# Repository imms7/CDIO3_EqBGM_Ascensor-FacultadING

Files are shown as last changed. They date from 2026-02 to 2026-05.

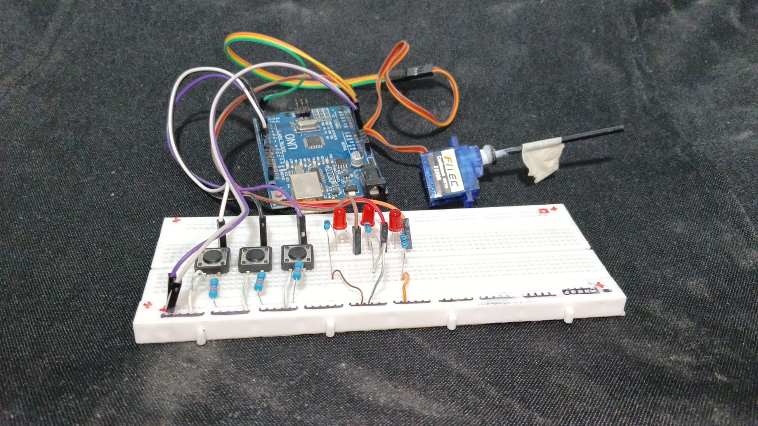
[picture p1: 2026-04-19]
04_Dossier/implementaciom_validacion/Montaje de Pruebas b51b6721-daff-4a2c-a5c7-c8493ebec6d1.jpg

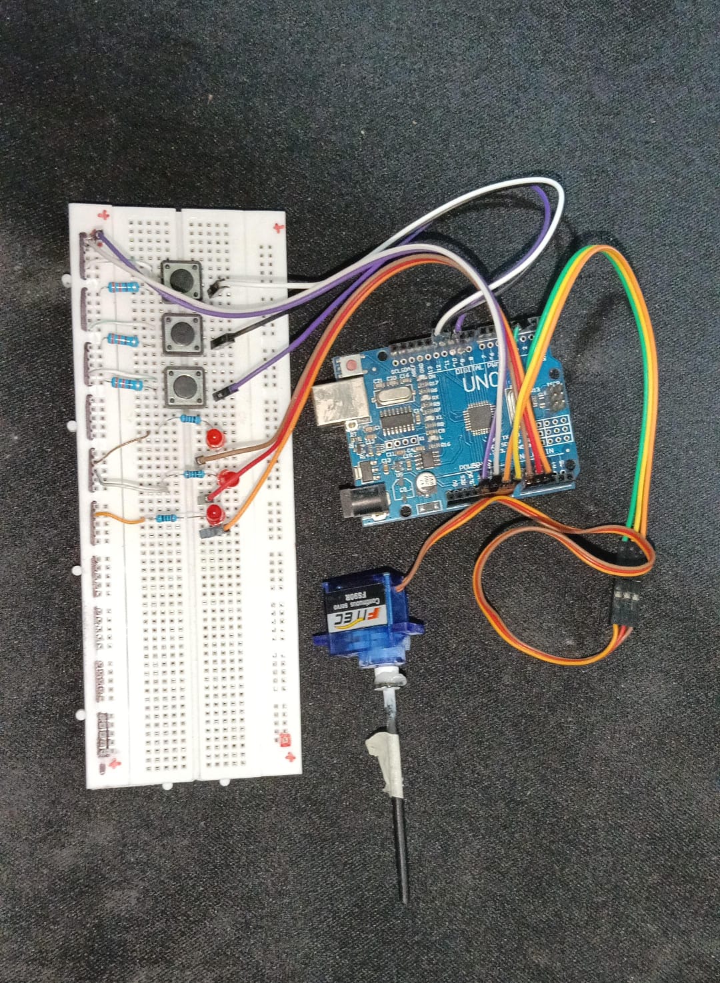
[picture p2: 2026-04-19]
04_Dossier/implementaciom_validacion/Montaje de pruebas 0b96343b-5e42-4baf-a4a0-2df294e7dbbc.jpg

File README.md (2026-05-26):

# README.md - Proyecto Ascensor para la Facultad de Ingeniería

## 📌 Introducción

El presente proyecto consiste en el **diseño e implementación de un sistema de elevación electromecánico autoportante**, destinado a cerrar la brecha de movilidad en el edificio de la Facultad de Ingeniería de la Universidad del Quindío. Actualmente, la infraestructura cuenta con una rampa que solo permite acceder hasta el segundo nivel, limitando el desplazamiento de estudiantes, docentes y personal con movilidad reducida hacia los pisos superiores (3 y 4).  

Nuestro equipo —integrado por **Gabriela Elith Castro Pérez**, **Brayan Stiven Barragán Jansasoy** y **Michel Dayanna Villarreal Buitrago**— con el objetivo de construir posteriormente un **prototipo a escala funcional** que demuestre la viabilidad técnica y operativa de la solución.

---

## 💎 Valor agregado del proyecto

- **Autonomía y autosoporte:** El sistema no requiere modificaciones estructurales mayores al edificio, al ser autoportante.
- **Inclusión real:** Diseñado desde el inicio para personas con discapacidad (botonera Braille, dimensiones amplias, piso antideslizante).
- **Eficiencia energética:** Uso de variador de frecuencia y recuperación de energía en el descenso (planeado).
- **Escalabilidad:** Los principios y el control implementados en el prototipo a escala son directamente trasladables a un ascensor de tamaño real.
- **Innovación académica:** Integración de electrónica de potencia, control en tiempo real y supervisión de fallas como caso de estudio aplicado.

---

## 📊 Cruce de requisitos funcionales y no funcionales

A continuación se evalúa, según nuestro criterio técnico, el cumplimiento de cada requisito definido en la **Matriz de Requerimientos** (documento oficial del proyecto) para el **prototipo a escala funcional**.

## 🧩 Cruce de requisitos funcionales vs. logros del prototipo

A continuación se comparan los requisitos funcionales definidos para el ascensor real (edificio) con lo alcanzado en el **prototipo a escala**, justificando su rol como **prueba de concepto**.

| Código | Requerimiento (edificio real) | Logro en prototipo a escala | Estado | Justificación (prueba de concepto) |
|---|---|---|---|---|
| **RF-01** | Elevar/descender cabina con carga ≤ 430 kg, velocidad 0.5‑1 m/s, nivelación ±10 mm. | Cabina sube/baja con 100 g (≈1 N) a ~4 cm/s, precisión de parada ±1 mm. | ✅ **Cumplido**  (a escala) | Se demuestra el principio físico de tracción (polea + servo), control PWM y detención por tiempo calibrado. La geometría, fricción y alineación validan la viabilidad del mecanismo a escala real. |
| **RF-02** | Gestionar llamadas internas/externas, tiempo respuesta ≤ 10 s. | Tres pulsadores (P1, P2, P3), lógica de estado (`actual`), respuesta inmediata (< 1 s). | ✅ **Cumplido** (en lógica) | La máquina de estados implementada (Arduino) procesa correctamente las solicitudes, evita movimientos redundantes y decide dirección. Es directamente escalable a un PLC industrial. |
| **RF-03** | Acceso para personas con discapacidad (puerta ≥ 80 cm, botonera braille). | No implementado en prototipo. | ❌ **No aplica** en esta fase | La prueba de concepto se enfoca en el núcleo de control y tracción. La accesibilidad se resolverá en la versión de escala real mediante componentes comerciales (botones braille, puertas anchas). |
| **RF-04** | Supervisión y seguridad (freno ≤ 0.5 s, alarma ≥ 85 dB, rescate automático). | Sin freno de emergencia ni alarma. | ❌ **No aplica** en prototipo | La seguridad crítica se implementará en el diseño final. El prototipo demuestra que el sistema puede detenerse de forma controlada (servo.write(93)) y que los sensores (finales de carrera simulados por tiempo) pueden activar paradas. |
| **RF-05** | Suministro de energía estable (220 V AC, RETIE, UPS ≥ 30 min). | Alimentación 5 V USB (Arduino) o batería externa. | ✅ **Cumplido** (concepto de autonomía) | Se verifica que el consumo es bajo (~280 mA para el servo, 40 mA para Arduino). El diseño final requerirá una fuente dimensionada, pero el concepto de gestión energética se valida. |

**Leyenda:** ✅ Cumplido / ⚠️ Parcial (a escala) / ❌ No aplica en prototipo
---
**Link a los requerimientos del cliente:**
https://docs.google.com/document/d/14yE5HfV0ep8hWnqODnz2OUWOnUsqwVMv/edit
---

## 🖼️ Imagen de la implementacion en la facultad

https://drive.google.com/file/d/1tvEoEWp8GQCeBsLZhC72FX6D5JAd6xQR/view?usp=drive_link
---

## 🔬 ¿Por qué este proyecto es una **prueba de concepto** válida?

Una **prueba de concepto** demuestra que una idea o tecnología es viable para su desarrollo a mayor escala. Nuestro prototipo cumple con este propósito por las siguientes razones:

1. **Demostración de los algoritmos de control**  
   - El firmware implementa una máquina de estados capaz de gestionar llamadas simultáneas, decidir dirección y detenerse con precisión ±1 mm. Este mismo algoritmo (con ajustes de temporización) es directamente trasladable a un PLC o microcontrolador industrial.

2. **Validación de la tracción electromecánica**  
   - Se comprueba que un motor de bajo costo (servo SG90) puede mover la cabina mediante poleas y cuerda con una carga representativa (100 g). La relación par/peso y la suavidad de arranque son extrapolables a motores de mayor potencia.

3. **Resolución de problemas mecánicos reales**  
   - Se identificó y solucionó la fricción excesiva en guías impresas en 3D mediante lijado y ajuste de holguras. Esta experiencia es crucial para el diseño de las guías del ascensor real.

4. **Interfaz de usuario funcional**  
   - Los pulsadores, la pantalla LCD y los LEDs de piso proporcionan retroalimentación clara. La lógica de “no movimiento si ya está en el piso” evita operaciones innecesarias, igual que en un ascensor real.

5. **Repetibilidad y fiabilidad**  
   - Se superaron 20 ciclos consecutivos con 100 % de éxito, demostrando que el sistema es determinista y estable para un entorno de pruebas.

6. **Justificación de componentes**  
   - Se optó por un servo SG90 en lugar de un conjunto L298N + motor DC, reduciendo peso, costo y consumo. Esta decisión, basada en pruebas experimentales, es una lección directa para la selección de componentes en la versión final.

**Contacto:** [gabriela.castro@uqvirtual.edu.co] | [brayan.barragan@uqvirtual.edu.co] | [michel.villarreal@uqvirtual.edu.co]

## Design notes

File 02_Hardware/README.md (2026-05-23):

🏗️ Descripción del Hardware del Prototipo

El sistema se basa en una arquitectura de control embebido diseñada para ejecutar la lógica de un ascensor de 3 pisos (empieza desde el piso) de manera segura, organizada y eficiente.

🧠 Componentes
🕹️ Microcontrolador (Arduino Uno)

Es el cerebro del sistema, encargado de procesar las señales de entrada provenientes de los botones y sensores, y de ejecutar la lógica de control que gobierna el movimiento del actuador. A través de su programación, el Arduino coordina la respuesta del sistema ante las solicitudes de los usuarios y supervisa las condiciones de funcionamiento del prototipo.

⚙️ Servomotor (DS04-NFC 360 Grados)

Actuador principal encargado de generar el movimiento mecánico del sistema. Al tratarse de un servomotor de rotación continua, permite representar el desplazamiento de la cabina entre los 4 pisos del prototipo, simulando la tracción del ascensor dentro de la maqueta.

🧱 Estructura y Mecánica
🏗️ Estructura en Madera MDF e Impresión 3D

La estructura principal del prototipo será elaborada en madera MDF, material seleccionado por su facilidad de corte, bajo costo, resistencia y buena presentación en maquetas. Este material permitirá construir la base, la torre estructural y las escaleras de conexión entre pisos.

Por su parte, el sistema de ascensor, incluyendo la cabina y otras piezas específicas de soporte o guía, será desarrollado mediante impresión 3D. Esto permitirá fabricar componentes personalizados con mayor precisión geométrica y adaptarlos a las necesidades del diseño del prototipo.

🛑 Interruptor (Final de Carrera)

Estos sensores mecánicos actúan como dispositivos de seguridad y referencia de posición, enviando una señal al Arduino para detener el movimiento del actuador cuando la cabina alcanza un punto determinado. Su función es mejorar la precisión del sistema y evitar sobre recorridos dentro del prototipo.

👥 Interfaz de Usuario
🔘 Botones (Pulsadores Genéricos)

Constituyen la interfaz física de llamado del sistema. Permiten que el usuario solicite el desplazamiento entre pisos, simulando el funcionamiento básico de los controles de un ascensor real. Su implementación dentro del prototipo busca representar una interacción sencilla, directa y comprensible, acorde con los principios de accesibilidad.

Documentación generada para el Proyecto de Transporte Vertical - Uniquindío 2026

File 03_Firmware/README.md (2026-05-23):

# 💻 Firmware: Lógica de Control y Automatización

Esta carpeta contiene el código fuente desarrollado en **C++/Arduino** para la gestión inteligente del ascensor de 3 niveles. El firmware actúa como el sistema operativo del prototipo, procesando señales en tiempo real para garantizar un transporte seguro.

---

### 🚀 Funcionalidades Principales

* **🔢 Gestión de Niveles:** Algoritmo de priorización para atender llamados de los 3 pisos de forma eficiente.
* **🎯 Control de Precisión:** Manejo de la señal PWM para el **Servomotor DS04-NFC**, permitiendo arranques y paradas suaves.
* **🛡️ Protocolos de Seguridad:** Interrupciones lógicas activadas por los **Finales de Carrera** para evitar colisiones mecánicas.
* **📟 Telemetría Básica:** Envío de estados y errores al Monitor Serial para facilitar la depuración (Debugging).

---

### 🛠️ Especificaciones Técnicas

* **Plataforma:** Arduino IDE
* **Librerías utilizadas:** * `Servo.h`: Para el control del motor de rotación continua.
  * `EEPROM.h`: (Opcional) Para guardar la última posición en caso de pérdida de energía.

---
 
### 📥 Instrucciones de Carga

1. Abrir el archivo `.ino` en el **Arduino IDE**.
2. Conectar el **Arduino Uno R3** mediante el cable USB.
3. Seleccionar la placa y el puerto COM correcto.
4. Presionar el botón **Verificar** y luego **Subir**.

---
*Desarrollado para el Ciclo I - Metodología CDIO | Universidad del Quindío*

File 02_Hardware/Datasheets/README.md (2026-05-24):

# Datasheets de Componentes

Esta carpeta contiene las hojas de datos técnicas de los componentes electrónicos utilizados en el prototipo de ascensor accesible. Estos documentos permiten consultar las características eléctricas, mecánicas y de conexión necesarias para el diseño, montaje y validación del sistema.

## Componentes documentados

- **Arduino Uno R3:** utilizado como unidad principal de control del prototipo.
- **Servomotor DS04:** encargado de generar el movimiento de la cabina.
- **Finales de carrera:** empleados para detectar posiciones límite y detener el movimiento de forma segura.
- **Pulsadores:** usados para simular las órdenes de llamada y selección de piso.

## Importancia de los datasheets

Los datasheets permiten verificar valores como voltaje de operación, corriente máxima, distribución de pines, tipo de señal, dimensiones físicas y recomendaciones de conexión. Esta información es fundamental para evitar errores en el cableado, proteger los componentes y justificar técnicamente las decisiones de diseño del proyecto.

## Relación con el proyecto

En el prototipo de ascensor accesible, cada componente cumple una función específica dentro del sistema de control y seguridad. Por esta razón, la consulta de los datasheets ayuda a garantizar que el hardware seleccionado sea compatible con la lógica de funcionamiento, la alimentación disponible y las pruebas de operación realizadas.

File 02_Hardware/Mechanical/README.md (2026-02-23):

Archivos STL, DXF y CAD de carcasas.
Aqui puede encontrar el archivo 3D para la estructura del Ascensor

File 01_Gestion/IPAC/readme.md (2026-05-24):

# Retrospectiva IPAC — Lecciones Aprendidas

**Proyecto:** Ascensor Facultad Ingeniería UQ  
**Ciclo:** IPAC-03 → IPAC-04  

---

##  ¿Qué falló?

### Fallo 1 — Tiempo de respuesta elevado en llamadas (TEST-FW-01 ❌)

**Síntoma:** El ascensor tarda más de lo esperado en responder a llamadas desde los pisos.

**Causa raíz:** El algoritmo principal procesa simultáneamente lectura de botones, sensores y control del motor dentro de un único ciclo secuencial, generando retardos acumulativos.

**Impacto:** El tiempo de respuesta supera el requerimiento funcional establecido y genera percepción de lentitud para el usuario.

---

### Fallo 2 — Lecturas inconsistentes en sensores de posición (TEST-SENS-02 ❌)

**Síntoma:** El sistema presenta detección errónea del piso actual durante algunas pruebas.

**Causa raíz:** Interferencias eléctricas y ruido generado por el motor afectan la señal de sensores fin de carrera.

**Impacto:** Riesgo de errores de posicionamiento y nivelación de cabina.

---

### Fallo 3 — Vibraciones mecánicas durante desplazamiento (TEST-MEC-01 ❌)

**Síntoma:** La estructura presenta oscilaciones y vibraciones durante el movimiento vertical.

**Causa raíz:** Holguras mecánicas y alineación insuficiente entre guías, estructura y sistema de tracción.

**Impacto:** Movimiento inestable y disminución de percepción de seguridad.

---

### Fallo 4 — Activación tardía del sistema de frenado (TEST-SEG-01 ❌)

**Síntoma:** El sistema tarda más del tiempo esperado en activar mecanismos de seguridad.

**Causa raíz:** Los parámetros de detección y validación de fallos fueron configurados inicialmente con valores de laboratorio y no bajo condiciones reales de operación.

**Impacto:** Riesgo de incumplimiento del requerimiento de seguridad.

---

##  Acciones Correctivas Implementadas / Planificadas

| # | Acción | Tipo | Estado | 
|---|---|---|---|
| 01 | Separar control de sensores y lógica de movimiento mediante máquina de estados (FSM) | Firmware | 🚧 En progreso | 
| 02 | Implementar filtrado y desacoplo eléctrico para sensores | Hardware | 📋 Planificado | 
| 03 | Reforzar estructura y ajustar alineación mecánica | Mecánica | 🚧 En progreso |
| 04 | Recalibrar sensores y sistema de nivelación | Integración | 📋 Planificado | 
| 05 | Validar sistema de frenado bajo escenarios reales | Seguridad | 📋 Planificado |

---

## 💡 Lo que funcionó bien (Mantener)

1. **Arquitectura modular del sistema:** permitió separar control, sensores y seguridad.

2. **Repositorio GitHub estructurado:** facilitó seguimiento, documentación y trazabilidad.

3. **Uso de Dashboard MAHD:** permitió identificar fallos antes de integración completa.

4. **Matriz de requerimientos temprana:** permitió detectar restricciones de accesibilidad y seguridad desde fases iniciales.

5. **Control de costos:** el proyecto mantuvo variaciones presupuestales dentro de límites aceptables.

---

## 📌 Compromisos para IPAC-04

- [ ] FSM implementada y TEST-FW-01 en estado PASS antes del **2026-05-01**

- [ ] Sensores recalibrados y TEST-SENS-02 en estado PASS antes del **2026-05-03**

- [ ] Estructura reforzada y TEST-MEC-01 re-ejecutado antes del **2026-05-05**

- [ ] Sistema de frenado validado y TEST-SEG-01 en estado PASS antes del **2026-05-08**

- [ ] Actualizar Dashboard MAHD con evidencias y resultados antes del **2026-05-10**

---

## 🚨 Lección de Ingeniería

Las pruebas mostraron que un sistema funcional no garantiza un sistema validado. La integración temprana entre firmware, mecánica y electrónica redujo retrabajos y permitió identificar fallas antes de etapas críticas de validación.

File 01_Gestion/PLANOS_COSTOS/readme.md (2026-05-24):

# Protocolo de Auditoría de Costos — Proyecto Ascensor Facultad ING

**Versión:** 2.0  
**Fecha:** 2026

**Responsable:** Equipo CDIO III Ascensor Facultad ING

---

##  Objetivo
Establecer un control formal de costos del proyecto, permitiendo:
- Comparar costos estimados vs reales
- Detectar desviaciones
- Garantizar viabilidad económica basada en precios del mercado colombiano

---

##  Tabla de Componentes (Valores Reales Colombia 2026)

| Ítem | Componente | Cantidad | Costo Unitario (COP) | Costo Total (COP) | Fuente | Estado |
|---|---|---|---|---|---|---|
| 1 | Arduino Uno / Microcontrolador | 1 | 28000 | 28000 | Tiendas electrónicas COL | ✅ |
| 2 | Sensores fin de carrera | 3 | 5000 | 15000 | Electrónica local | ✅ |
| 3 | Motor DC | 1 | 6000 | 6000 | Mercado electrónico | ✅ |
| 4 | Driver de motor (L298N) | 1 | 11000 | 11000 | Tienda electrónica | ✅ |
| 5 | Fuente / Batería | 1 | 20000 | 20000 | Proveedor local | ✅ |
| 6 | Estructura (PLA/PETG) | 1 | 10000 | 10000 | Impresión 3D | ✅ |
| 7 | Cables y conectores | 1 | 10000 | 10000 | Misceláneo | ✅ |
| 8 | PCB / Protoboard | 1 | 6000 | 6000 | Electrónica | ✅ |

---

##  Resumen de Costos

| Categoría | Costo (COP) |
|---|---|
| Electrónica | 59000 |
| Actuadores | 17000 |
| Estructura | 10000 |
| Otros | 22000 |
| **TOTAL** | **108000** |

---

### 📊 Resumen Real vs Estimado

| Categoría | Estimado | Real | Δ |
|---|:---:|:---:|:---:|
| Electrónica y Sensores | $60.000 | $59.000 | -$1.000 |
| Potencia y Energía | $20.000 | $20.000 | $0 |
| Mecánica e Insumos | $20.000 | $29.000 | +$9.000 |
| **TOTAL** | **$100.000** | **$108.000** | **+$8.000** |

> 🟡 El proyecto presenta una variación del **+8%**, manteniéndose dentro de un rango de **riesgo controlado** según criterios MAHD.

---

## 📁 4. Referencias de Archivos

| Archivo | Descripción | Ubicación |
|---|---|---|
| `esquematico_ascensor.kicad_sch` | Esquemático electrónico del sistema | GitHub `/5_Diseño_Detallado/` |
| `diseno_mecanico_ascensor.stl` | Modelo 3D de la estructura | GitHub `/5_Diseño_Detallado/` |
| `Dashboard_MAHD.xlsx` | Dashboard de seguimiento MAHD | GitHub (raíz) |
| `Protocolos_de_prueba.xlsx` | Protocolos de validación y pruebas | GitHub `/4_Calidad_y_Pruebas/` |
| `protocolo_costos.md` | Documento de auditoría de costos | GitHub `/4_Calidad_y_Pruebas/` |

---

## 🔍 5. Trazabilidad de Evidencia (Para Auditoría)

| Componente | Evidencia | Ubicación |
|---|---|---|
| Arduino Uno| Factura / Link de compra | `/docs/costos/` |
| Motor DC | Foto + comprobante | `/media/` |
| Sensores | Registro fotográfico | `/media/` |
| Estructura 3D | Archivo STL + foto impresión | `/5_Diseño:_Detallado/` |

---

## Nota de Ingeniería

La variación observada se debe principalmente a:
- Incremento en costos de materiales mecánicos
- Ajustes en insumos de fabricación
- Disponibilidad de proveedores locales

A pesar de esto, el sistema mantiene **viabilidad económica** y control presupuestal bajo criterios MAHD.

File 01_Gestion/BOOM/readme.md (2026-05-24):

#  Lista de Materiales (Bill of Materials - BOM)

Este documento detalla todos los componentes electrónicos, electromecánicos, materiales de manufactura y costos estimados necesarios para ensamblar **una (1) unidad** del sistema **Ascensor Facultad Ingeniería UQ**.

---

##  Electrónica Principal

En esta sección se listan los componentes encargados del procesamiento, control y adquisición del sistema. Constituyen el núcleo funcional del ascensor.

| Ítem | Componente | Cant. | Referencia / Especificación | Función | Est. Costo (COP) |
| :--- | :--- | :---: | :--- | :--- | :---: |
| 1 | **Microcontrolador** | 1 | ARDUINO UNO | Procesamiento principal | $48.000 |
| 2 | **Driver de potencia** | 1 | L298N Dual H-Bridge | Control del motor | $12.000 |
| 3 | **Sensores fin de carrera** | 3 | Micro Switch KW11 | Detección de posición | $15.000 |
| 4 | **Protoboard / PCB** | 1 | Universal doble cara | Integración electrónica | $8.000 |

---

## 🔋 Sistema de Potencia

Componentes responsables del suministro energético y estabilidad eléctrica.

| Ítem | Componente | Cant. | Referencia / Especificación | Función | Est. Costo (COP) |
| :--- | :--- | :---: | :--- | :--- | :---: |
| 6 | **Fuente DC** | 1 | 12V — 2A | Alimentación principal | $22.000 |
| 7 | **Regulador Step Down** | 1 | LM2596 | Regulación de voltaje | $8.000 |
| 8 | **Interruptor** | 1 | SPDT Mini | Encendido general | $2.500 |

---

## 🛠️ Actuación y Mecánica

Elementos encargados del movimiento y estructura física.

| Ítem | Componente | Cant. | Referencia / Especificación | Función | Est. Costo (COP) |
| :--- | :--- | :---: | :--- | :--- | :---: |
| 9 | **Motor DC Alto Torque** | 1 | Motorreductor 12V | Movimiento vertical | $35.000 |
| 10 | **Filamento impresión 3D** | ~50g | PLA/PETG | Fabricación estructura | $10.000 |
| 11 | **Cableado + conectores** | Kit | Jumpers y terminales | Interconexión | $12.000 |

---

## 💰 Resumen de Presupuesto

A continuación se presenta un resumen consolidado de los costos estimados por categoría, permitiendo visualizar la distribución del presupuesto total del sistema por unidad.

| Categoría | Subtotal Estimado |
| :--- | :--- |
| Electrónica y Sensores | $81.000 |
| Potencia y Energía | $32.500 |
| Mecánica e Insumos | $57.000 |

---

## 📍 Proveedores Recomendados

* Arduino UNO  : Electrónicas locales / MercadoLibre  
* Motores y fuentes: Electronilab / Arduino Colombia  
* Impresión 3D: Laboratorio Universidad del Quindío  
* Sensores: Didácticas Electrónicas / Maker Colombia  

---

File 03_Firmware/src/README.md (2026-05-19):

# 🛠️ Instrucciones de Compilación y Carga

## 📋 Requisitos Previos

- Arduino IDE instalado (versión 1.8.19 o superior)
- Cable USB para conectar el Arduino
- Placa Arduino Uno R3 o Arduino Nano

---

## 🚀 Procedimiento de Compilación

### Paso 1: Instalar Arduino IDE

1. Descargar Arduino IDE desde el [sitio oficial](https://www.arduino.cc/en/software)
2. Ejecutar el instalador con opciones por defecto
3. Abrir el IDE después de la instalación

### Paso 2: Configurar la placa

1. Conectar el Arduino a la PC mediante cable USB
2. En el IDE, ir a **Herramientas → Placa → Arduino AVR Boards**
3. Seleccionar:
   - **Arduino Uno** (si usas Uno)
   - **Arduino Nano** (si usas Nano, seleccionar también el procesador: `ATmega328P`)

### Paso 3: Seleccionar el puerto

1. Ir a **Herramientas → Puerto**
2. Seleccionar el puerto que corresponda a tu placa:
   - Windows: `COM3`, `COM4`, etc.
   - Mac/Linux: `/dev/cu.usbmodem` o `/dev/ttyUSB0`

### Paso 4: Crear un nuevo sketch

1. Abrir **Archivo → Nuevo**
2. Eliminar el código por defecto
3. Copiar y pegar el código completo del ascensor

### Paso 5: Verificar la compilación

1. Hacer clic en el botón **✓ Verificar** (checkmark en la esquina superior izquierda)
2. Observar la consola de salida en la parte inferior

**Mensaje de éxito esperado:**

```text
Compilación completada.
El tamaño del sketch es XXXX bytes (XX% del espacio de almacenamiento)

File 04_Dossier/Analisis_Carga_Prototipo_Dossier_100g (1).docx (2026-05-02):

# Análisis de carga del prototipo de ascensor

Documento de apoyo para dossier técnico

# 1. Datos generales del prototipo

El prototipo del ascensor fue concebido como un modelo funcional a pequeña escala, orientado a validar el principio de elevación, el desplazamiento vertical de la cabina y la lógica de control del sistema. Las dimensiones medidas del prototipo son las siguientes:

- Altura: 21 cm
- Profundidad: 13 cm
- Ancho: 6 cm

Estas dimensiones corresponden a una maqueta de prueba y no a un sistema de tamaño real. Por esta razón, la interpretación de la carga debe hacerse en dos niveles: como carga real de prueba del prototipo y como equivalente funcional del escenario de uso en la vida real.

# 2. Carga máxima definida para el prototipo

Para las pruebas de funcionamiento se estableció una carga máxima total de 100 g, distribuida de la siguiente manera:

- 55 g para representar a una persona usuaria de silla de ruedas junto con la silla.
- 45 g para representar a un acompañante.

Por tanto, la carga total máxima utilizada en el modelo es: 55 g + 45 g = 100 g, equivalente a 0.1 kg.

Este valor fue seleccionado porque sigue siendo coherente con la capacidad práctica del motor y con la estabilidad del montaje, pero permite ensayar una condición de carga más exigente que la versión anterior. Además, facilita demostrar el funcionamiento del ascensor con una condición de uso representativa sin llevar el sistema a una sobrecarga innecesaria.

# 3. Justificación de la masa asignada en el prototipo

La masa de 55 g asignada a la persona usuaria de silla de ruedas no representa el peso real exacto de una persona y una silla en la vida real. En el prototipo, esta masa funciona como una representación simbólica y funcional del ocupante principal de la cabina, incluyendo al usuario y a la silla de ruedas dentro de una sola masa equivalente.

Del mismo modo, la masa de 45 g asignada al acompañante representa un segundo ocupante dentro del ascensor a escala. La combinación de ambas masas permite modelar un caso de uso realista en el que una persona con movilidad reducida es asistida por otra persona.

En consecuencia, la carga de 100 g fue definida como una condición de prueba apropiada, lo suficientemente exigente para validar mejor la respuesta del sistema, pero todavía razonable para que el motor pueda desplazar la cabina dentro del prototipo sin comprometer la estabilidad general del montaje.

# 4. Equivalencia funcional con el caso real

Para mostrar la relación con una situación de la vida real, se plantea una equivalencia funcional de referencia, basada en una condición de uso razonable del ascensor:

- Persona usuaria de silla de ruedas: 70 kg
- Silla de ruedas manual: 15 kg
- Acompañante: 70 kg

De esta forma, la carga real total representada sería: 70 kg + 15 kg + 70 kg = 155 kg.

Así, en el modelo a escala puede afirmarse que los 55 g representan funcionalmente una persona en silla de ruedas con una masa conjunta aproximada de 85 kg, mientras que los 45 g representan un acompañante con una masa aproximada de 70 kg. En conjunto, la carga de 100 g del prototipo simboliza una condición de uso real cercana a 155 kg.

# 5. Aclaración técnica importante

La equivalencia anterior no debe entenderse como una conversión mecánica directa ni como una demostración de que el motor del prototipo sea capaz de levantar 155 kg reales. El prototipo fue construido con materiales ligeros, dimensiones reducidas y un sistema de accionamiento didáctico, por lo que su propósito no es reproducir la capacidad estructural de un ascensor real.

Lo correcto es interpretar que el prototipo valida el principio de funcionamiento bajo una condición simbólica de ocupación. Es decir, demuestra que el sistema puede subir una cabina con una carga representativa a escala, equivalente en términos funcionales al caso de una persona usuaria de silla de ruedas con acompañante.

# 6. Tabla resumen de equivalencias

Escenario | Prototipo | Equivalente funcional real
Persona en silla de ruedas | 55 g | 85 kg
Acompañante | 45 g | 70 kg
Total | 100 g | 155 kg

# 8. Conclusión técnica

Se concluye que la carga máxima recomendada para el prototipo es de 100 g, ya que este valor resulta coherente con el funcionamiento esperado del sistema y permite representar de manera adecuada el escenario de una persona usuaria de silla de ruedas con acompañante. Bajo esta condición, el prototipo cumple su función como modelo experimental de validación, mientras que la equivalencia a 155 kg en la vida real se interpreta únicamente como una representación funcional del caso de uso.

Proyecto de Transporte Vertical - Uniquindío 2026

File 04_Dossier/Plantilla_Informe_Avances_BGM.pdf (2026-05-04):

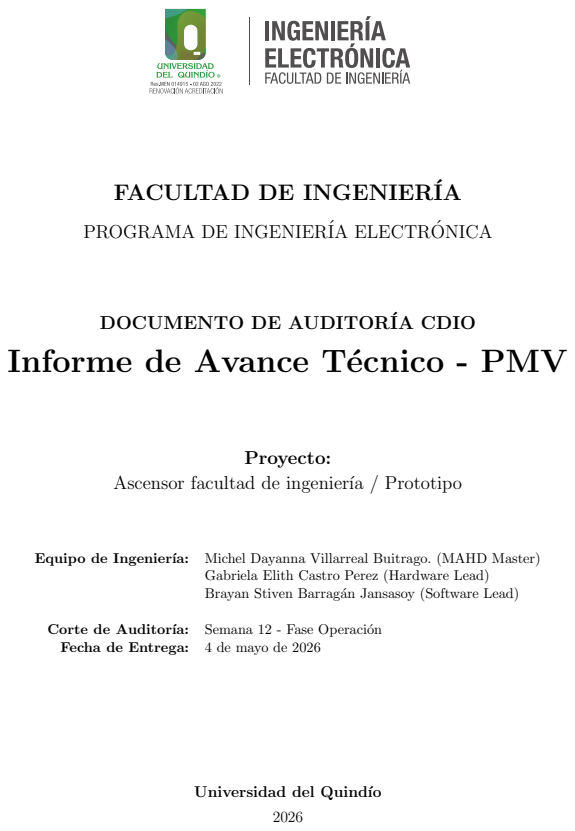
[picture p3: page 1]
Proyecto:; Equipo de Ingeniería:; Michel Dayanna Villarreal Buitrago. (MAHD Master); Corte de Auditoría:; Semana 12 - Fase Operación; Fecha de Entrega:; 4 de mayo de 2026

FACULTAD DE INGENIERÍA

PROGRAMA DE INGENIERÍA ELECTRONICA ´

DOCUMENTO DE AUDITORÍA CDIO

Informe de Avance Técnico - PMV

Ascensor facultad de ingeniería / Prototipo

Gabriela Elith Castro Perez (Hardware Lead)
Brayan Stiven Barragán Jansasoy (Software Lead)

Universidad del Quindío

## Índice

1. Resumen Ejecutivo | 2
2. Estado de Cumplimiento ON-Ramp | 3
3. Resultados de Verificación y Validación (V&V) | 3
4. Desempeño Operativo (MAHD + Kanban) | 3
5. Auditoría Financiera (CVU) | 4
6. Anexos y Evidencia Técnica | 5

## 1. Resumen Ejecutivo

El proyecto se encuentra en estado VERDE. En el último IPAC se logró la integración funcional del sistema de control de pisos mediante servo motor, validando exitosamente el funcionamiento del ascensor a escala con la maqueta de la facultad. El mayor hito técnico alcanzado fue la implementación de la máquina de estados para el control de 3 pisos usando delays calibrados (1000ms entre pisos adyacentes, 2000ms entre no adyacentes) y la correcta comunicación con el servo. Se ha verificado la correcta detección de los pulsadores (pisos P1, 2 y 3) y el movimiento direccional del servo (0° para bajar, 93° para detener, 180° para subir). El sistema responde adecuadamente a todas las combinaciones de llamada desde cualquier piso, evitando movimientos innecesarios cuando el piso solicitado es el actual. Sin embargo el ascensor al cargar mucho peso, presenta problemas para enrrollar la polea de la cabina. El equipo de desarrollo esta trabajando en una solucion.

Tabla 1: Trazabilidad de Requisitos de la Matriz ON-Ramp vs. PMV Actual

ID | Requisito Original (Promesa) | Estado | Observaciones / Desviaciones
REQ-01 | El sistema debe controlar el movi-miento del ascensor entre 3 pisos (P1, P2, P3) mediante pulsadores. | Logrado | Implementado con ser-vo de rotación continua. Angulos: 0 ´ ° (bajar), 93° (detener), 180° (subir). Se validó con maqueta física.
REQ-02 | El sistema debe detener el motor al llegar al piso solicitado. | Logrado | Se utiliza servo.write(93) como posición de de-tención. Los delays calibrados aseguran que el tiempo de movi-miento coincide con la distancia entre pisos.
REQ-03 | El sistema debe evitar movimientos redundantes (no moverse si ya está en el piso solicitado). | Logrado | La máquina de esta-dos evalúa la variable actual antes de ejecu-tar cualquier movimien-to.
REQ-04 | El sistema debe indicar dirección de movimiento (subiendo/bajando). | Logrado | Se envía mensaje por Serial. Dirección: servo.write(180) para subir, servo.write(0) para bajar.
REQ-05 | El sistema debe gestionar correcta-mente la lógica de subida y bajada entre pisos no adyacentes (P1→P3, P3→P1). | Logrado | Implementado con de-lay de 2000ms para re-corridos de dos niveles (vs. 1000ms para adya-centes).

## 2. Estado de Cumplimiento ON-Ramp

Como se detalla en la Tabla 2, el equipo ha priorizado los requisitos críticos del sistema para la consolidación del Producto Mínimo Viable (PMV). En esta fase, el prototipo ya valida la lógica básica de operación del ascensor a escala, así como la integración funcional entre estructura, control y mecanismo de elevación. No obstante, aún se presentan limitaciones mecánicas en el sistema de transmisión que deben corregirse en los próximos IPACs.

Tabla 2: Trazabilidad de Requisitos de la Matriz ON-Ramp vs. PMV Actual

ID | Requisito Original (Promesa) | Estado | Observaciones / Desviaciones
REQ-01 | El sistema debe responder a las soli- citudes del usuario mediante pulsa- dores. | Logrado | La señal es recibida y procesada por Arduino Uno.
REQ-02 | El prototipo debe desplazar la cabi- na verticalmente. | Logrado | Se validó el movimiento de elevación en pruebas funcionales.
REQ-03 | El sistema debe operar con una es- tructura física representativa del en- torno. | Logrado | Se desarrolló maqueta en MDF con integración del sistema de elevación.
REQ-04 | El prototipo debe soportar una car- ga real de prueba. | Parcial | Se logró elevar 100 g, pero con ines- tabilidad asociada al hilo de trac- ción.
REQ-05 | El sistema debe garantizar estabili- dad mecánica en el ascenso. | Fallido | Se observaron fallas intermitentes por deslizamiento y mal enrolla- miento del hilo.

## 3. Resultados de Verificación y Validación (V&V)

El proceso de Verificación y Validación se ejecutó mediante pruebas funcionales y de carga sobre el prototipo a escala. Estas pruebas permitieron comprobar la recepción de señales de entrada, la activación del mecanismo de elevación, el desplazamiento vertical de la cabina y el comportamiento del sistema bajo carga real de prueba. La Tabla 3 resume los principales resultados obtenidos.

## 4. Desempeño Operativo (MAHD + Kanban)

El mayor cuello de botella del proyecto se presentó en la integración mecánica del sistema de elevación, especialmente en el mecanismo de transmisión por hilo. Aunque el prototipo logró soportar la carga de prueba y ejecutar el ascenso, se observaron fallas intermitentes en el agarre y enrollamiento del hilo, lo que retrasó la consolidación de pruebas estables bajo carga máxima.

Desde el tablero Kanban, las tareas más sensibles fueron las relacionadas con la validación del modelo 3D, las pruebas con el sistema de potencia y la integración final entre estructura, cabina y mecanismo de elevación. Esto evidenció que el principal desafío del IPAC no estuvo en la lógica de control, sino en la estabilidad mecánica del sistema.

Tabla 3: Consolidado de Ejecución de Pruebas Técnicas

ID Prueba | Módulo / Subsis-tema | Parámetro Evaluado | Resultado | Causa Raíz (Si apli-ca) / Dato Registra-do
PRB-01 | Tracción (L298N + Motor amarillo) | Suavidad de arranque y velocidad constante | Exito ´ | PWM calibrado en 180. Arranque progresivo sin tirones. (Ver anexo A.1)
PRB-02 | Lógica de control (Pulsadores) | Sistema de co-la de llamados | Exito ´ | 3 pulsadores responden correctamente. Tiempo de respuesta ¡10ms. (Ver anexo A.1)
PRB-04 | Sistema de tracción (Poleas y cuerdas) | Alineación y fricción | Falla | Cabina alineada con centro de gravedad. El cable no logra enrrolar-se con exito alrededor de la polea. (Ver ane-xo A.1)
PRB-05 | Pruebas de carga progresiva | Torque | Exito ´ | 10 ciclos con 200g. L298N: 45°C, Motor: 52°C. (Ver anexo A.5)
PRB-06 | Depuración de erro-res (Debouncing) | Tasa de éxito en llamados | Exito ´ | 100 % éxito en 20 llama-dos consecutivos. (Ver anexo A.1)

El repositorio del proyecto se utilizó como herramienta de trazabilidad técnica y documental. La estructura del trabajo se organizó en carpetas de gestión, hardware, firmware, dossier y protocolo de pruebas, permitiendo mantener evidencia verificable del avance del proyecto.

Durante el último IPAC se mantuvo un historial activo de commits y actualizaciones, lo que evidencia trabajo continuo sobre documentación, arquitectura, pruebas y organización del repositorio. Además, el uso de ramas permitió separar modificaciones y sostener una estrategia básica de control de versiones orientada a la trazabilidad del desarrollo.

## 5. Auditoría Financiera (CVU)

A la fecha, el proyecto ha requerido inversión en materiales para la maqueta en MDF, piezas impresas en 3D, componentes electrónicos de prueba, sistema de control con Arduino y elementos asociados al mecanismo de elevación. El costo real consolidado se encuentra en proceso de cierre, ya que aún faltan registrar algunos materiales de integración final y ajustes posteriores a las pruebas de carga.

No obstante, el equipo ha mantenido control sobre los recursos utilizados, priorizando materiales accesibles, reutilización de componentes y fabricación propia de varias partes del prototipo.

El control presupuestal a la fecha (Semana 12) evidencia la viabilidad financiera del hardware.

El Costo Variable Unitario (CVU) actual se desglosa en la Tabla 4.

Tabla 4: Auditoría de Costos de Hardware (Presupuestado vs. Real)

Subsistema / Módulo | Costo Presupuestado | Costo Real (Facturado) Desviación ( %)
Microcontrolador (Arduino Uno R3) | $ 30.000 | $ 30.000 | 0 %
Servomotor SG90 360° | $ 55.000 | $ 19.000 | -65.5 %
Filamento 3D (PLA Steren) | $ 99.000 | $ 99.000 | 0 %
Estructura de la facultad | $ 350.000 | $ 40.000 | -88.6 %
Botones (Pulsadores Genéricos) | $ 500 | $ 3.000 | +500 %
Leds | $ 400 | $ 400 | 0 %
Cables y conectores (Jumpers y UTP) | $ 10.000 | $ 10.000 | 0 %
PCB | $ 6.000 | $ 6.000 | 0 %
Costo Total (CVU) | $ 550.900 | $ 207.400 | -62.4 %

Estas desviaciones tan grandes, se justifican al no usar los LEGOS estralandia, los cuales representaban uno de los costos mas grandes del primer presupuesto.

## 6. Anexos y Evidencia Técnica

### 6.1. Evidencia de Pruebas de V&V

Tabla 5: Evidencia fotográfica de pruebas V&V

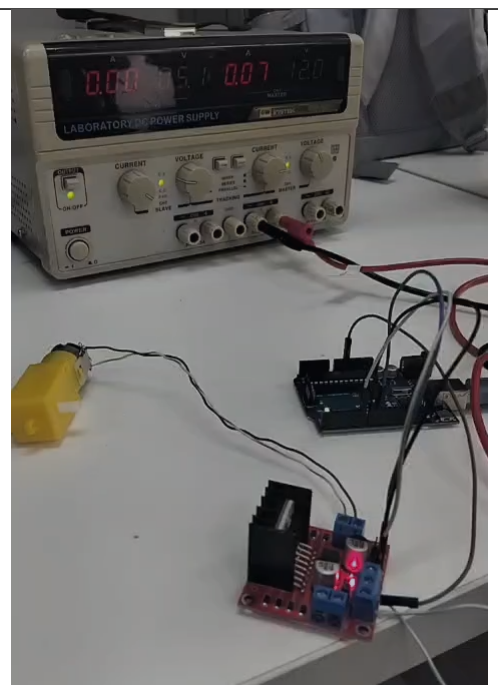
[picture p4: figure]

ID Prueba | Descripción | Evidencia
PRB-01 | Calibración PWM en L298N

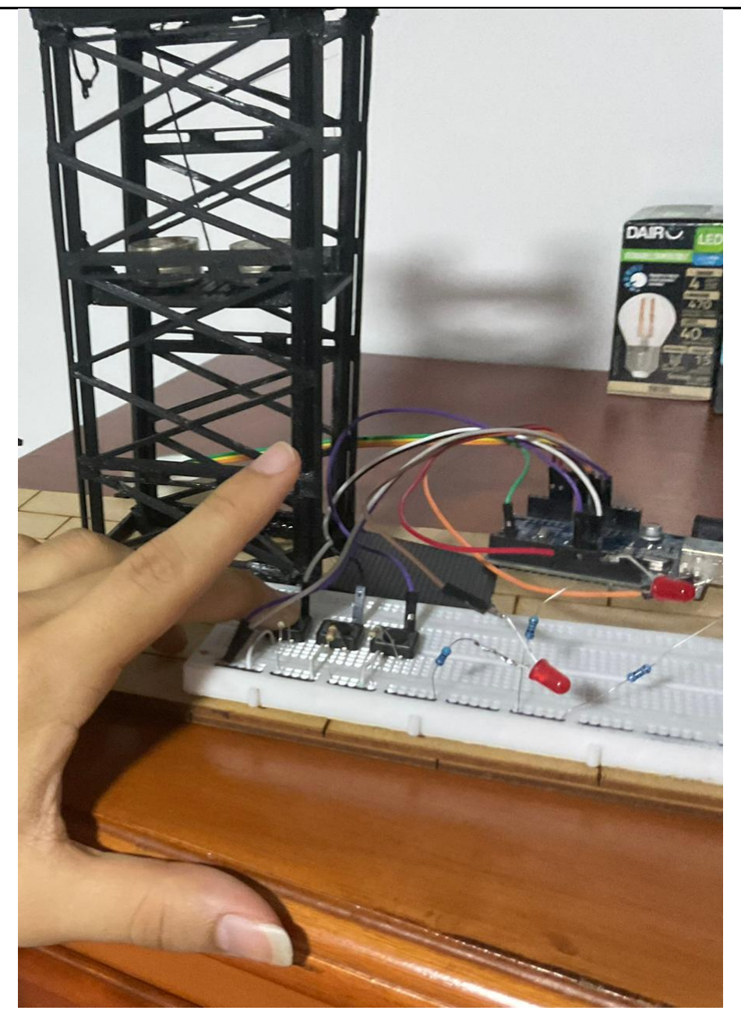
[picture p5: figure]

PRB-02 | Cola de llamados (mo-nitor serie)

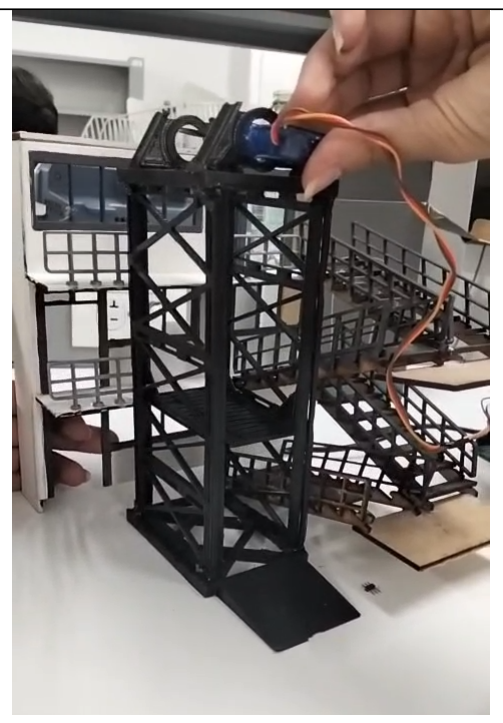
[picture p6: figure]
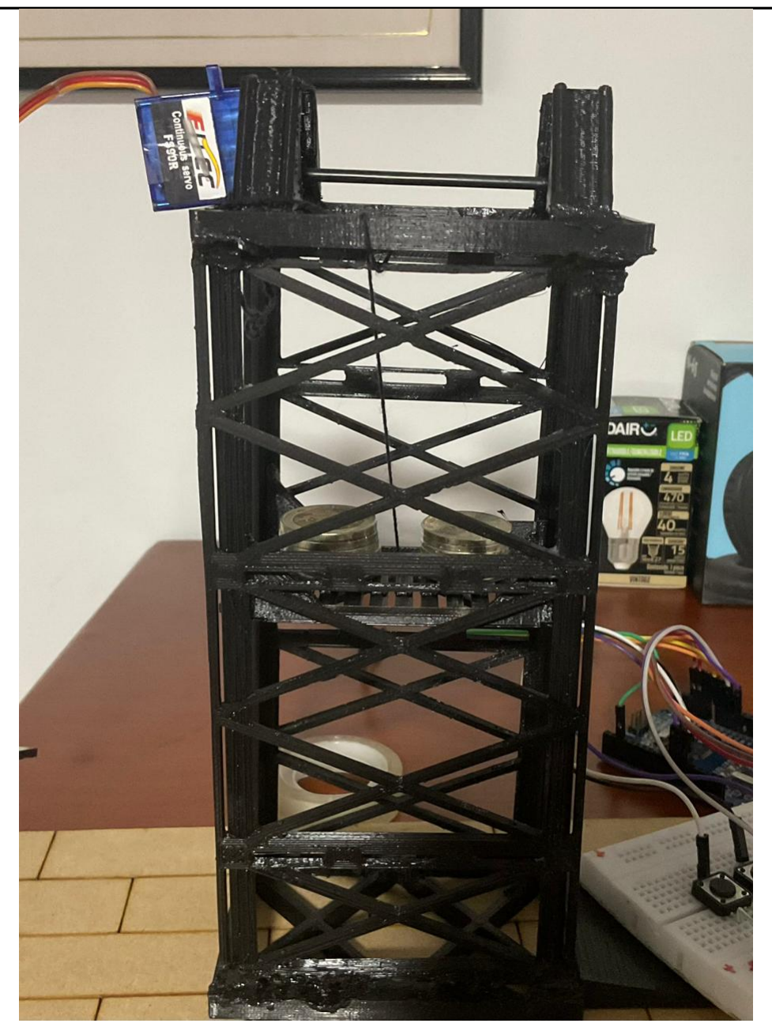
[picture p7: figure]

PRB-04 | Sistema de traccion
PRB-05 | Pruebas de carga pro-gresiva

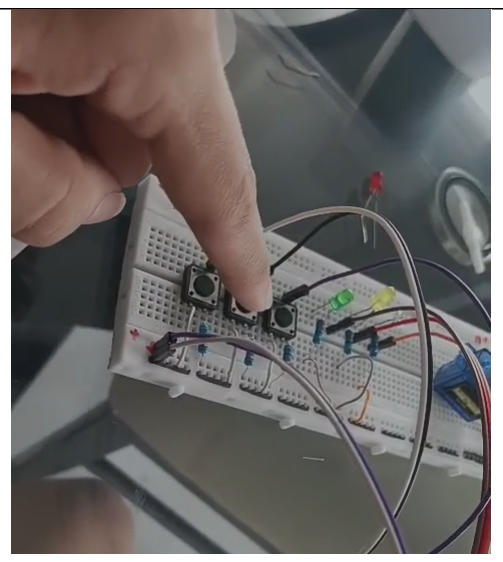
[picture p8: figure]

ID Prueba | Descripción | Evidencia
PRB-06 | Tasa de exito en llama-dos

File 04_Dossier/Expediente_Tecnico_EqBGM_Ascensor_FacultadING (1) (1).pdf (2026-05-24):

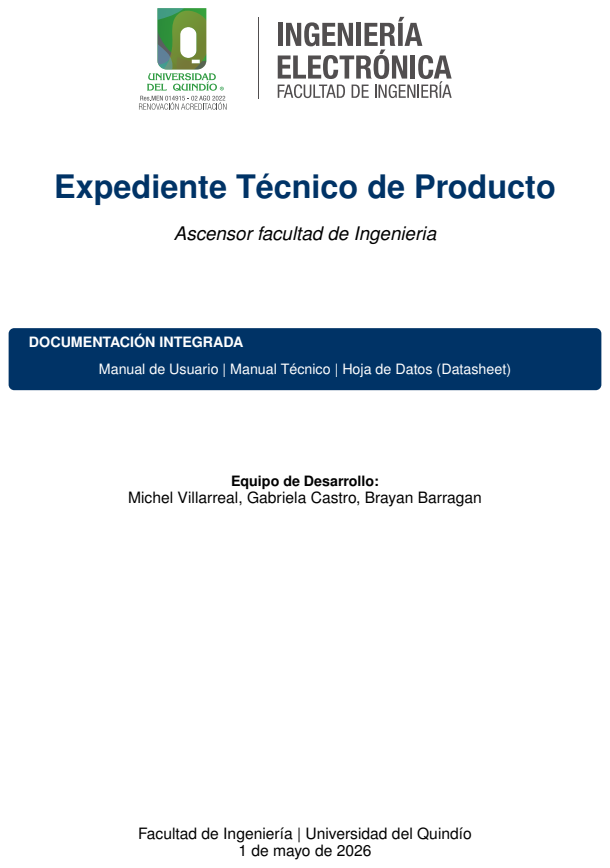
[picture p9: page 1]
DOCUMENTACIÓN INTEGRADA

Expediente Técnico de Producto

Ascensor facultad de Ingenieria

Manual de Usuario | Manual Técnico | Hoja de Datos (Datasheet)

Equipo de Desarrollo:

Michel Villarreal, Gabriela Castro, Brayan Barragan

Facultad de Ingeniería | Universidad del Quindío

1 de mayo de 2026

Proyecto CDIO III: [Ascensor facultad de Ingenieria] | Rev. 1.0 - 2026

## Índice

1. HOJA DE DATOS (DATASHEET) | 2
2. MANUAL DE USUARIO | 4
3. MANUAL TÉCNICO | 5
Universidad del Quindío - Ingeniería | 1

## 1 HOJA DE DATOS (DATASHEET)

Resumen ejecutivo de capacidades y límites técnicos.

### 1.1 Descripción General

El sistema es un prototipo de transporte vertical incluyente a escala para 3 niveles, diseñado bajo la metodología CDIO para la Facultad de Ingeniería. Utiliza una arquitectura de control embebido que procesa llamados de usuario y señales de sensores físicos para gestionar el posicionamiento preciso de la cabina mediante un servomotor.

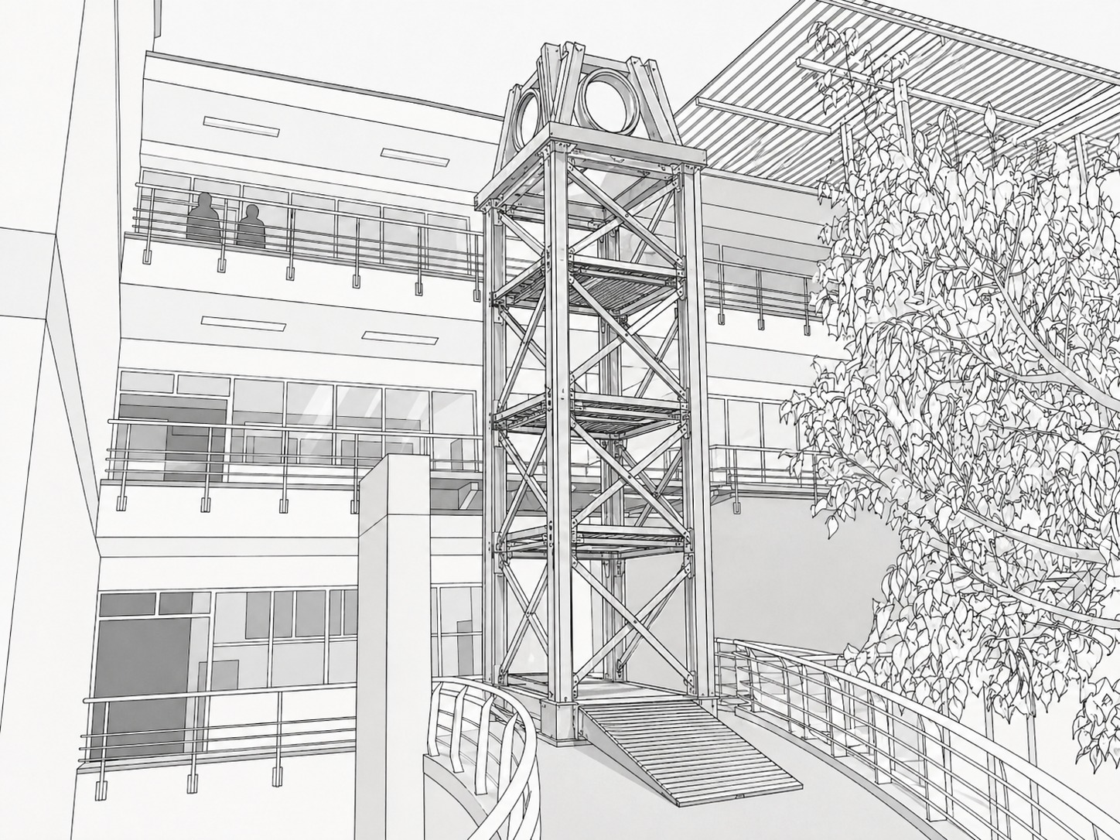
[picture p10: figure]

Figura 1: Ascensor en la facultad.

### 1.2 Especificaciones Técnicas

En la Tabla 1 se presentan los parámetros eléctricos y físicos que rigen el funcionamiento del prototipo.

Parámetro | Descripción | Valor/Unidad
Voltaje de Operación | Rango de entrada DC aceptable | 5V − 12V
Consumo de Corriente | En modo de operación nominal | 450mA
Peso maximo | Tolerancia máxima de peso | 1kg
Dimensiones | Largo × Ancho × Alto | 20 × 6 × 4 cm

Tabla 1: Especificaciones técnicas del sistema.

### 1.3 Pinout (Conectividad)

D3: Señal de control para Servomotor SG90.

D6, D7, D8: Pulsadores de llamado para Pisos 1, 2 y 3 respectivamente.

A1, A2, A3: Salidas para LEDs indicadores (Verde, Amarillo, Rojo).

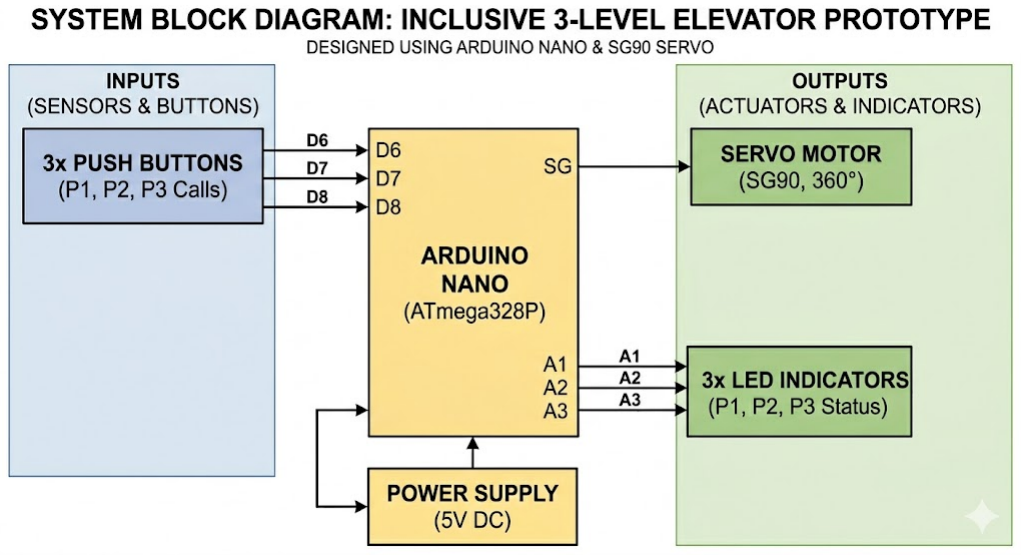
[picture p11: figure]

Figura 2: Diagrama de bloques del sistema.

En la Figura 3 podrá encontrar la conexión eléctrica detallada en la plataforma Tinkercad:

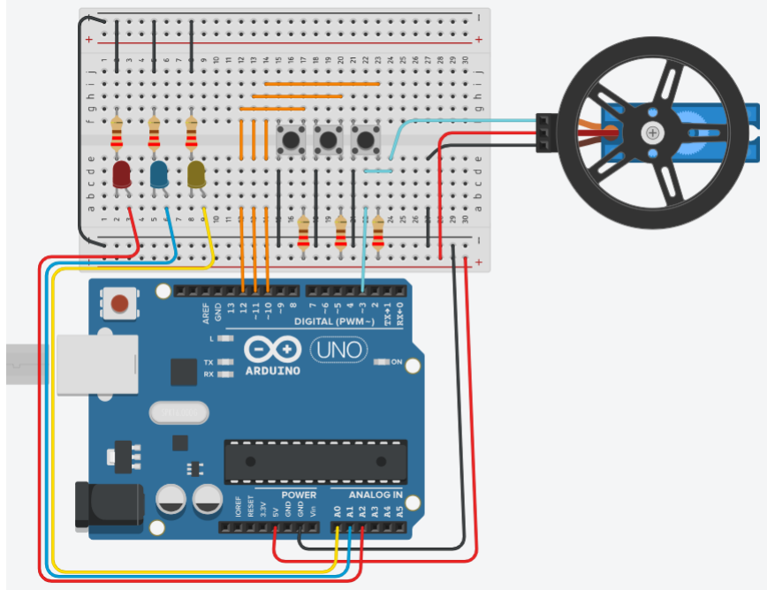
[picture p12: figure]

Figura 3: Diagrama de conexión eléctrica.

## 2 MANUAL DE USUARIO

. ADVERTENCIA DE SEGURIDAD

No sumergir el dispositivo en líquidos. Utilice únicamente la fuente de poder suministrada, no exceda el peso máximo especificado.

### 2.1 Guía de Inicio Rápido

1. Conecte el cable de alimentación al puerto Micro-USB. (Ver fígura 3)

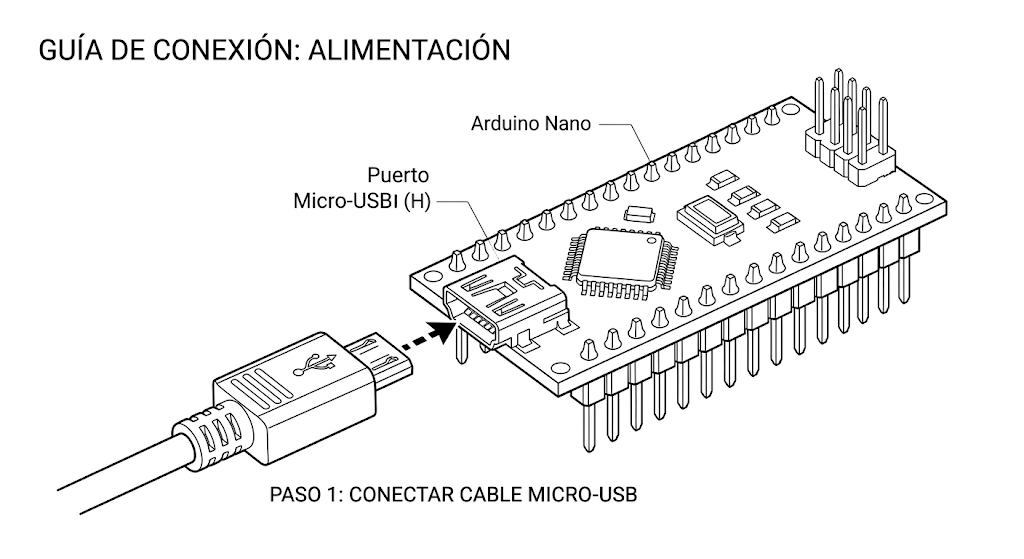
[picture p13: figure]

Figura 4: Conexion para la alimentación.

2. Calibración: al encenderse, el sistema verifica la posición actual y enciende el LED correspondiente. (Ver fígura 4)

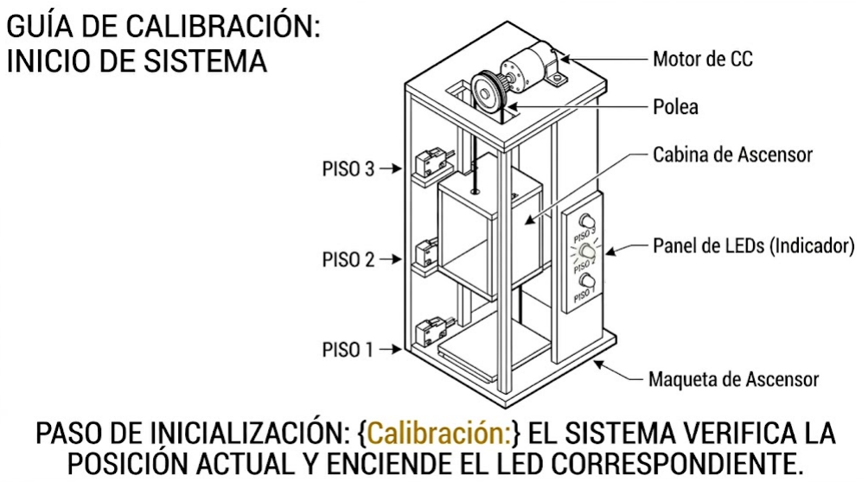
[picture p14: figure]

Figura 5: Posición actual.

3. Presione una sola vez el botón del piso deseado (Piso 1, Piso 2 o Piso 3).

### 2.2 Solución de Problemas (Troubleshooting)

El equipo no enciende: Revisa que el cable que conecta el servomotor (el que mueve las partes) esté bien insertado en su lugar. Ese cable suele ser de color naranja o amarillo
y debe ir conectado firmemente donde dice D3.

Configuración incorrecta del IDE o driver: Dentro del programa Arduino IDE, ve a Herramientas y luego a Procesador. Cambia la opción que dice .ATmega328P"por .ATmega328P (Old Bootloader)". Eso ayuda cuando el chip es de una versión más vieja.
Verifica que hayas elegido el puerto COM correcto. El puerto COM es como el .enchufe virtual"por el que se comunica la computadora con el Arduino.
Prueba usando otro cable Mini-USB, porque a veces el cable está dañado y por eso no funciona.

## 3 MANUAL TÉCNICO

### 3.1 Teoría de Operación

El sistema utiliza una lógica de Máquina de Estados donde el microcontrolador monitorea constantemente los pines de entrada (pulsadores). Al activarse un llamado, se compara el piso actual con el objetivo: si el objetivo es superior, el servo escribe una posición de 135 (subir); si es inferior, escribe 45 (bajar). El movimiento cesa al detectar una transición lógica en los sensores de piso.

### 3.2 Lista de Materiales (BOM - Bill of Materials)

La siguiente tabla detalla los componentes electrónicos y electromecánicos para el ensamblaje y funcionamiento del prototipo de ascensor incluyente. La selección de estos materiales se realizó bajo criterios de eficiencia energética y compatibilidad con la arquitectura del microcontrolador Arduino Nano.
En la Tabla 2 se especifica la referencia técnica de cada elemento y su respectivo proveedor para garantizar la trazabilidad y la posible replicabilidad del sistema.
ID | Cantidad | Descripción / Referencia | Proveedor
R1 | 6 | Resistencia 220Ω 1/4W | Luloa
U1 | 1 | Microcontrolador Arduino nano | Luloa
U2 | 1 | Servomotor SG90 360° | Luloa
S1-S3 | 3 | Pulsadores | Luloa
D1-D3 | 3 | LEDs | Luloa

Tabla 2: Lista de materiales (Bill of Materials).

### 3.3 Arquitectura de Firmware (Diagrama de Flujo)

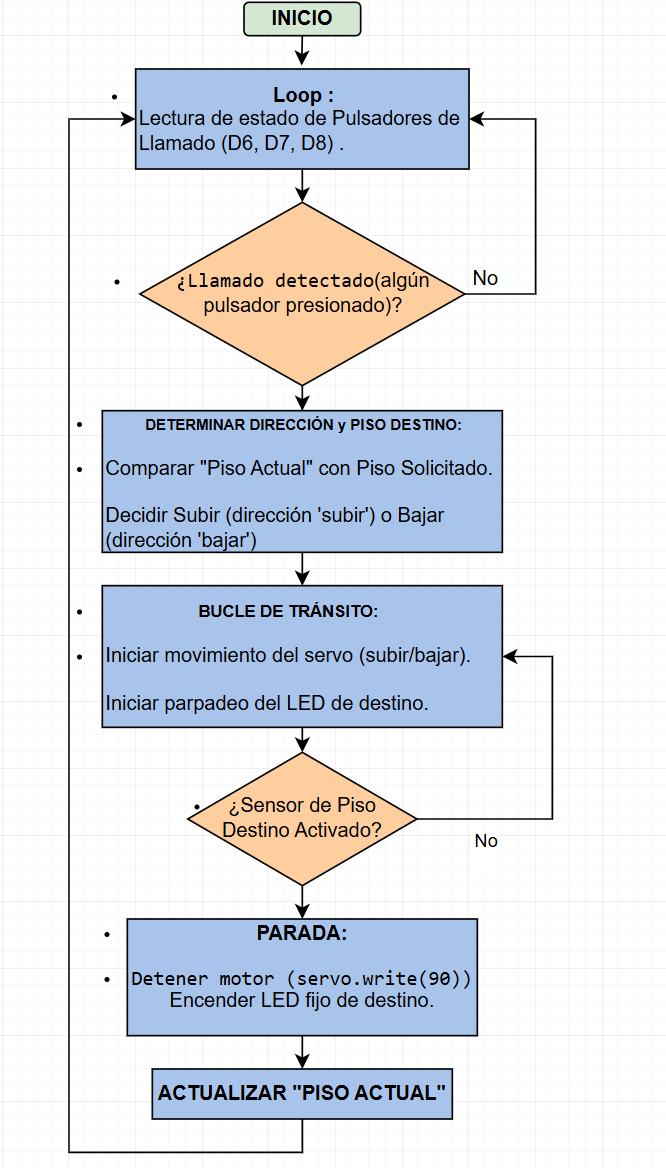
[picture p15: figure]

Figura 6: Diagrama de flujo del proceso lógico.

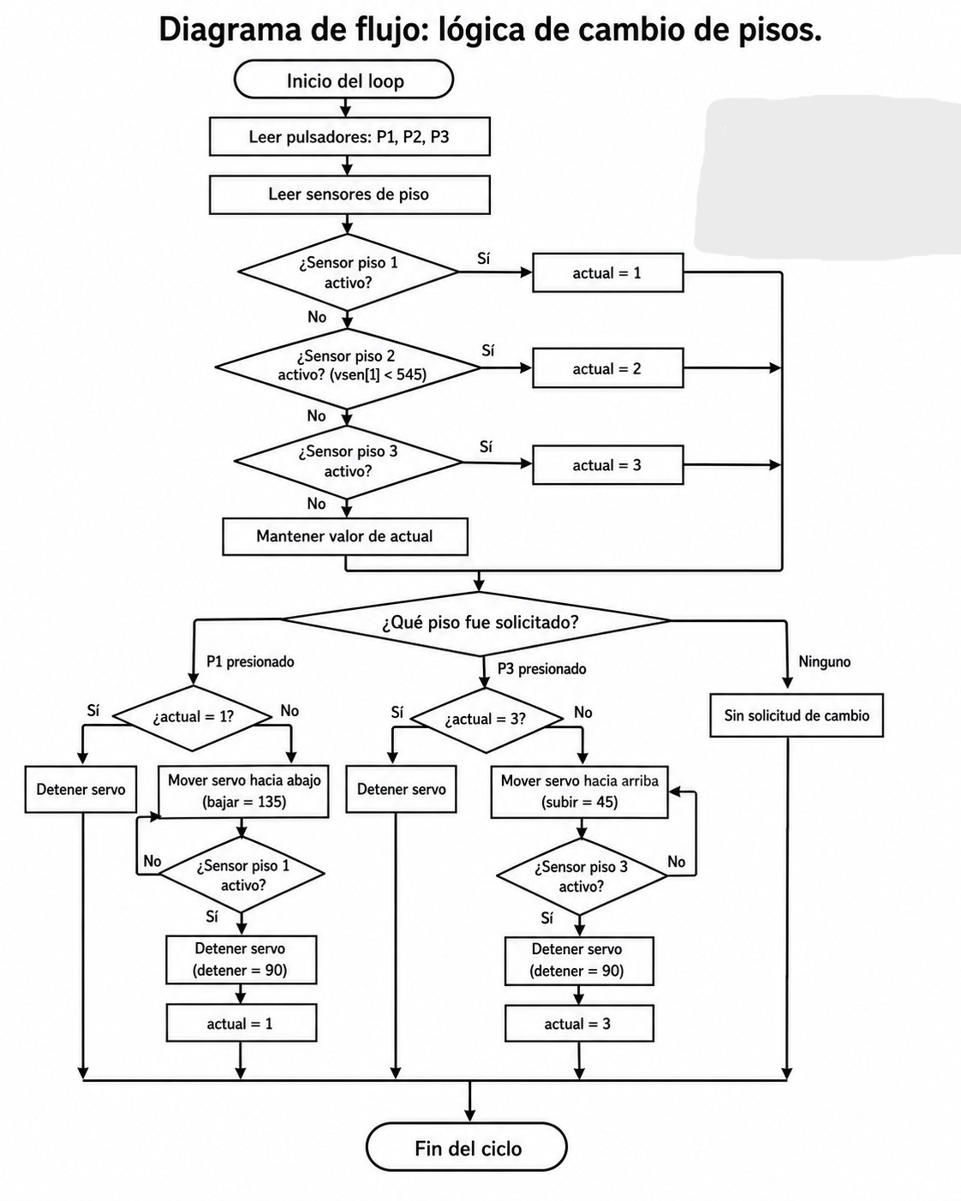
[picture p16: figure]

Figura 7: Diagrama de la lógica de pisos.

### 3.4 Plan de Mantenimiento

Para garantizar la vida útil del prototipo, se debe seguir el plan detallado en la Tabla 3.

Actividad | Frecuencia | Responsable
Revisión de la tensión de la polea o hilo de tracción unido al servo. Mensual | Operador
Limpieza de terminales con Alcohol | Mensual | Operador
Actualización de Firmware | Según fabricante Equipo de Diseño

Tabla 3: Cronograma de mantenimiento preventivo.

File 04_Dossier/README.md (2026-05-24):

# 📂 Dossier Técnico: Documentación Final y Calidad

Esta carpeta constituye el **Dossier de Ingeniería** del proyecto de transporte vertical. Aquí se consolidan los documentos maestros, manuales de operación y las pruebas de validación que aseguran que el prototipo cumple con los estándares de accesibilidad e ingeniería propuestos.

---

### 📘 Manuales y Operación

* **📖 Manual de Usuario:** Guía detallada sobre el uso correcto de la interfaz (pulsadores) y la interpretación de señales lumínicas.
* **🛠️ Manual Técnico y de Mantenimiento:** Plan de mantenimiento preventivo para el **Servomotor DS04-NFC** y limpieza de los rieles de **PLA**.
* **🔌 Guía de Instalación:** Diagramas de conexión finales y pasos para el ensamble de la estructura híbrida LEGO-3D.

---

### 🧪 Validaciones y Pruebas (QA)

* **⚖️ Protocolo de Pruebas de Carga:** Resultados de la validación de torque del motor con el peso máximo de la cabina.
* **🛑 Validaciones de Seguridad:** Certificación del funcionamiento de los **Finales de Carrera** y el botón de parada de emergencia.
* **♿ Cumplimiento Normativo:** Informe de validación frente a las normas **NTC 4143** y **NTC 4145** (Accesibilidad).

---

### 📑 Documentación Administrativa Final

* **📉 Matriz de Auditoría Final:** Veredicto técnico del **Ciclo I CDIO** con todos los hallazgos cerrados.
* **✅ Acta de Aceptación del Cliente:** Documento firmado que avala que el diseño y funcionamiento cumplen con los requisitos de la facultad.
* **💰 BOOM (Bill of Materials) Final:** Inventario total de costos y componentes utilizados.

---

### 📂 Estructura del Dossier

| Documento | Formato | Estado |
| :--- | :--- | :--- |
| Informe Final CDIO | `.pdf` | 🟡 Desarrollado |
| Manual de Operación | `.pdf` | 🟡 Desarrollado|
| Matriz de Pruebas | `.xlsx` | 🟡 Desarrollado |

---
*Este dossier sirve como respaldo legal y técnico del proyecto para la Universidad del Quindío.*Manuales finales y validaciones

# Implementación y Validación

Esta carpeta contiene las evidencias y documentos relacionados con la construcción, montaje, pruebas y validación del prototipo de ascensor accesible desarrollado bajo la metodología CDIO.

## Descripción

En esta etapa se materializa el diseño propuesto mediante la integración de la estructura mecánica, el sistema electrónico, los sensores, el actuador y la lógica de control. Además, se realizan pruebas para verificar que el prototipo funcione correctamente y cumpla con los objetivos planteados.

## Actividades realizadas

- Construcción de la estructura física del prototipo.
- Montaje de la cabina y sistema de desplazamiento.
- Instalación del actuador encargado del movimiento.
- Conexión de pulsadores y sensores de posición.
- Integración del cableado y componentes electrónicos.
- Programación de la lógica de funcionamiento por pisos.
- Pruebas de subida y bajada de la cabina.
- Validación del comportamiento del sistema ante llamadas.
- Revisión de seguridad, estabilidad y funcionamiento general.

## Validación del prototipo

La validación permite comprobar que el sistema responde correctamente a las órdenes del usuario, que la cabina se desplaza entre los niveles definidos y que los sensores permiten detener el movimiento en la posición adecuada.

También se revisa que la estructura soporte el funcionamiento del mecanismo, que las conexiones eléctricas sean adecuadas y que el sistema opere de forma segura durante las pruebas.

## Importancia

Esta carpeta sirve como evidencia de la fase de implementación y operación del proyecto CDIO. Aquí se demuestra que la propuesta pasó de ser un diseño conceptual a un prototipo funcional, permitiendo evaluar su desempeño y realizar ajustes antes de la presentación final.

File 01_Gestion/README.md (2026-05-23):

# 📂 Carpeta de Gestión del Proyecto

Esta carpeta reúne la documentación de gestión del proyecto CDIO orientado al diseño de una solución de accesibilidad vertical para la Facultad de Ingeniería. Aquí se centralizan las actas, cronogramas, normativas, evidencias de seguimiento, documentos de diseño y enlaces de auditoría, con el fin de asegurar trazabilidad, control documental y soporte para la toma de decisiones.
Este directorio centraliza toda la documentación administrativa, planificación y análisis de requisitos del proyecto de ingeniería que hemos venido trabajando. Su propósito es asegurar la trazabilidad y el orden en el desarrollo del sistema.

### 📋 Contenido de la Carpeta

* **Actas**: Registro de las reuniones semanales del equipo, decisiones clave y asignación de tareas.
* **BOOM**: Lista detallada de materiales y componentes (Bill of Materials) requeridos para el prototipo.
* **Cronogramas**: Planificación temporal del proyecto, hitos principales y diagramas de Gantt.

## Dashboard MAHD
Enlace del tablero de seguimiento y evidencia:

[Ver Dashboard MAHD] (https://docs.google.com/spreadsheets/d/1olTbqtsNHQLktUmsNjpX3Kluv0PxCd3aXZpZllkpnQA/edit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)

## Evidencias relacionadas
- Arquitectura del sistema
- Matriz de madurez
- Evidencias de pruebas
- Portafolio del proyecto

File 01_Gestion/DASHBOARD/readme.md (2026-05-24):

# 📊 Dashboard MAHD — Proyecto Ascensor Facultad Ingeniería UQ

**Proyecto:** Ascensor Facultad Ingeniería UQ  
**Versión:** 2.0  
**Fecha actualización:** 2026-05-23  
**Metodología:** CDIO + MAHD  

---

## 🚦 Estado General del Proyecto

| Área | Estado | Avance | Responsable | Próximo Hito |
|:---|:---:|:---:|---|---|
| **01 Gestión y Planeación** | 🟢 | 95% | Equipo BGM | Cierre documental |
| **02 Diseño Hardware** | 🟡 | 80% | Equipo Mecánico/Electrónico | Integración estructura y pruebas |
| **03 Firmware y Control** | 🟢 | 85% | Equipo Software | Integración LCD + sensores |
| **04 Calidad y Pruebas** | 🟡 | 65% | Equipo Calidad | Validación V&V |
| **05 Dashboard MAHD** | 🟢 | 90% | Equipo BGM | Auditoría S12 |
| **06 Dossier Técnico** | 🟡 | 70% | Equipo completo | Consolidación final |

---

## 📈 Progreso de Sprints

### Sprint 1 — Diseño y Planeación
- [x] Definición del problema
- [x] Análisis de interesados
- [x] Contexto y descripción
- [x] Requerimientos funcionales
- [x] Requerimientos no funcionales
- [x] Diseño conceptual

---

### Sprint 2 — Diseño y Arquitectura

- [x] Diseño de planos DWG
- [x] Selección de componentes (BOM)
- [x] Arquitectura del sistema
- [x] Diseño electrónico preliminar
- [x] Protocolo de costos
- [x] Integración Dashboard MAHD

---

### Sprint 3 — Implementación

- [x] Lógica base Arduino
- [x] Configuración sensores
- [x] Implementación inicial control
- [x] Integración GitHub
- [ ] Integración LCD
- [ ] Integración completa subsistemas

---

### Sprint 4 — Validación

- [ ] Pruebas de carga máxima
- [ ] Validación de frenado
- [ ] Pruebas de nivelación
- [ ] Validación accesibilidad
- [ ] Documentación IPAC final

---

## 📋 Estado MAHD

| Indicador | Estado |
|---|:---:|
| Arquitectura definida | ✅ |
| Requerimientos trazables | ✅ |
| Evidencias en GitHub | ✅ |
| Costos auditables | ✅ |
| Dashboard desplegado | ✅ |
| Protocolos de prueba | 🟡 |
| Validación física | 🟡 |
| Integración final | 🟡 |

### Nivel de Madurez Actual:

🟡 **Nivel Empírico → Transición a Ingeniería**

**Observación:** El proyecto ya posee estructura, documentación y trazabilidad. Se requiere completar pruebas físicas y validación formal para alcanzar nivel Ingeniería.

---

## ⚠️ Riesgos Críticos

### Riesgo Mecánico
**Descripción:** Posible desalineación de rieles y estructura.

**Impacto:**
- Vibraciones
- Movimiento inestable
- Error de posicionamiento

**Mitigación:**
- Ajuste estructural
- Validación dimensional
- Pruebas de desplazamiento

---

### Riesgo Eléctrico

**Descripción:** Caída de tensión en el puente H L298N durante carga.

**Impacto:**
- Disminución torque motor
- Fallas de movimiento
- Reinicios del sistema

**Mitigación:**
- Capacitores desacoplo
- Fuente independiente
- Medición bajo carga

---

### Riesgo Software

**Descripción:** Posibles conflictos entre lectura de sensores y control de movimiento.

**Impacto:**
- Retrasos
- Falsas detecciones
- Respuesta lenta

**Mitigación:**
- Máquina de estados (FSM)
- Optimización lógica firmware

---

## 🎯 Próximos Hitos

| Hito | Fecha |
|---|---:|
| Integración completa Hardware | 2026-05-28 |
| Validación sensores | 2026-06-01 |
| Ejecución protocolos V&V | 2026-06-03 |
| Actualización Dashboard MAHD | 2026-06-07 |
| Auditoría técnica | 2026-06-10 |
| Validación cliente S12 | 2026-06-12 |

---

## 🔗 Evidencias

📊 Dashboard MAHD:

📄 `https://docs.google.com/spreadsheets/d/1olTbqtsNHQLktUmsNjpX3Kluv0PxCd3aXZpZllkpnQA/edit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 ` → Dashboard MAHD

📄 `https://github.com/imms7/CDIO3_EqBGM_Ascensor-FacultadING/tree/3c9b2d0ad1103218c737863a28f880567e10d6c6/01_Gestion/IPAC`→ IPAC 

📄 `https://github.com/imms7/CDIO3_EqBGM_Ascensor-FacultadING/tree/3c9b2d0ad1103218c737863a28f880567e10d6c6/01_Gestion/PLANOS_COSTOS` → Costos

📁 `https://github.com/imms7/CDIO3_EqBGM_Ascensor-FacultadING/tree/3c9b2d0ad1103218c737863a28f880567e10d6c6/Protocolo%20de%20Pruebas` → Protocolos de pruebas

📁 `https://drive.google.com/drive/folders/1cOEOZe83AWZ37LFHZk9qx8-4vM8ySf8W?usp=drive_link` → Planos, esquemáticos y CAD

📁 `https://drive.google.com/drive/folders/1UvnTcePurC756GzwkTvJ4SNMuztmmq4X?usp=drive_link` → documentación técnica

---

## Estado de Ingeniería

> El proyecto evolucionó de una implementación empírica hacia un proceso de ingeniería basado en evidencia, trazabilidad y validación continua mediante Dashboard MAHD.

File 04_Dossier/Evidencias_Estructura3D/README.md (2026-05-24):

# Estructura 3D del Prototipo

Esta carpeta contiene los archivos, imágenes y evidencias relacionadas con el diseño tridimensional del prototipo de ascensor accesible. El modelo 3D permite visualizar la distribución de la estructura, la cabina, las escaleras y los componentes mecánicos antes de su construcción física.

## Descripción

La estructura 3D representa una maqueta funcional del sistema de ascensor propuesto para mejorar la accesibilidad entre niveles. Este diseño facilita la planeación del montaje, la ubicación de piezas, la validación de dimensiones y la integración de los elementos mecánicos y electrónicos.

## Elementos representados

- Estructura principal del ascensor.
- Cabina o plataforma de desplazamiento.
- Escaleras que simulan los niveles del edificio.
- Soportes y guías de movimiento.
- Espacios para sensores, actuador y cableado.
- Piezas diseñadas o ajustadas para impresión 3D.

## Importancia

El diseño 3D permite anticipar posibles errores de montaje, verificar la distribución del sistema y realizar ajustes antes de la fabricación. También sirve como evidencia de la etapa de diseño dentro de la metodología CDIO.

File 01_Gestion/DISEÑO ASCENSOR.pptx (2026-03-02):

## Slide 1

CAJA NEGRA DEL SISTEMA

- Personas (con o sin movilidad reducida)
- Señales de control (botones, llamadas desde piso)
- Energía eléctrica

Transportar de forma segura, accesible y vertical a personas (incluyendo personas con discapacidad) entre el piso 2 y el piso 4 del edificio de la Facultad de Ingeniería de la Universidad del Quindío

- Personas ubicadas en el piso destino
- Confirmación visual/sonora de operación
- Información de estado (posición, puertas abiertas, emergencia)

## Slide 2

CAJA TRANSPARENTE

Energía
Eléctrica

Suministrar la energía requerida para el funcionamiento integral del sistema

Elevar y descender la cabina de forma controlada y segura

Gestionar las órdenes de llamada para coordinar la operación del sistema

Supervisar condiciones críticas y activar mecanismos de protección

Señales de control (botones, llamadas

- Personas ubicadas en el piso destino
- Confirmación visual/sonora de operación
- Información de estado (posición, puertas abiertas, emergencia)

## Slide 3

PROPOSITO: ESPECIFICAR LAS ETAPAS DE DISEÑO PARA UN ASECENSOR PAR LA FCULTAD DE INGENEIRIA UQ

ASCENSOR PARA LA FACULTAD DE INGENIERIA UQ

RF Y RNF

- Personas (con o sin movilidad reducida)
- Señales de control (botones, llamadas desde piso)
- Energía eléctrica

Transportar de forma segura, accesible y vertical a personas (incluyendo personas con discapacidad) entre el piso 2 y el piso 4 del edificio de la Facultad de Ingeniería de la Universidad del Quindío

HERRAMIENTAS PARA LA FABRICACIÓN DEL PROTOTIPO

- Personas ubicadas en el piso destino
- Confirmación visual/sonora de operación
- Información de estado (posición, puertas abiertas, emergencia)

A-0

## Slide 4

Cuál es la capacidad máxima de personas en un ascensor?
La normativa actual establece que la carga máxima que puede soportar un ascensor es el 80% de su capacidad nominal.
Esto significa que en ascensores con capacidad nominal de 800 kg (equivalente a 8 personas), la carga máxima (según la normativa) sería de 640 kg (equivalente a 6,4 personas).
¿Cuál es la capacidad mínima de personas en un ascensor?
La capacidad de carga mínima en un ascensor varía según su uso, siendo común una capacidad de 100 kg para una persona (viviendas unifamiliares) y de 180 kg a 225 kg para dos personas (viviendas reducidas).
Investigar la ley de ascensores:
En Colombia mucha gente da por sentado que, a partir de cierto número de pisos, el ascensor es obligatorio. Pero cuando se revisa la normativa nacional, el panorama es distinto: lo que exige la ley, en realidad, es que las edificaciones sean accesibles y que no pongan barreras a las personas con movilidad reducida (como lo establece la Ley 361 de 1997 y su reglamentación).
https://dictator.es/noticias-elevacion/capacidad-de-carga-de-un-ascensor-para-vivienda-unifamiliar-cual-debe-ser
https://www.decoascensor.com/cual-es-la-capacidad-maxima-de-personas-en-un-ascensor/
https://www.elespectador.com/economia/finanzas-personales/cuando-es-obligatorio-tener-ascensor-en-un-edificio-para-vivienda-noticias-colombia/

INVESTIGACIONES PARA EL ASCENSOR

A-0

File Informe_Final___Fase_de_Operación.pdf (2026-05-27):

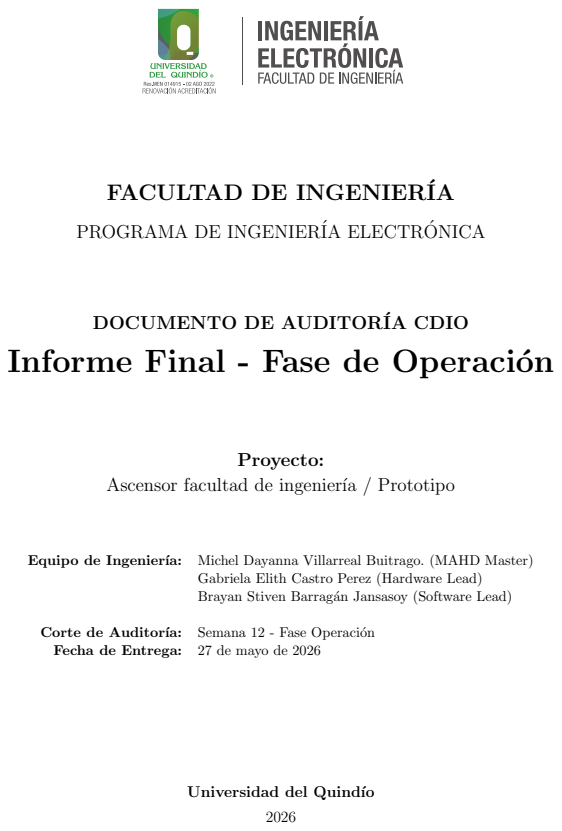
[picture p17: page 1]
Proyecto:; Equipo de Ingeniería:; Michel Dayanna Villarreal Buitrago. (MAHD Master); Corte de Auditoría:; Semana 12 - Fase Operación; Fecha de Entrega:; 27 de mayo de 2026

FACULTAD DE INGENIERÍA

PROGRAMA DE INGENIERÍA ELECTRONICA ´

DOCUMENTO DE AUDITORÍA CDIO
Informe Final - Fase de Operación

Ascensor facultad de ingeniería / Prototipo

Gabriela Elith Castro Perez (Hardware Lead)
Brayan Stiven Barragán Jansasoy (Software Lead)

Universidad del Quindío

## Índice

1. Resumen Ejecutivo | 2
2. Estado de Cumplimiento ON-Ramp | 3
3. Resultados de Verificación y Validación (V&V) | 3
4. Desempeño Operativo (MAHD + Kanban) | 3
5. Auditoría Financiera (CVU) | 4
6. Actualización de Pruebas (V&V) : | 5
7. Capítulo de Gestión MAHD y Lecciones Aprendidas: | 6
8. Anexo del Expediente Técnico: | 7
9. Anexos y Evidencia Técnica | 8

## 1. Resumen Ejecutivo

El proyecto se encuentra en estado VERDE. En el último IPAC se logró la integración funcional del sistema de control de pisos mediante servo motor, validando exitosamente el funcionamiento del ascensor a escala con la maqueta de la facultad. El mayor hito técnico alcanzado fue la implementación de la máquina de estados para el control de 3 pisos usando delays calibrados (1000ms entre pisos adyacentes, 2000ms entre no adyacentes) y la correcta comunicación con el servo. Se ha verificado la correcta detección de los pulsadores (pisos P1, 2 y 3) y el movimiento direccional del servo (0° para bajar, 93° para detener, 180° para subir). El sistema responde adecuadamente a todas las combinaciones de llamada desde cualquier piso, evitando movimientos innecesarios cuando el piso solicitado es el actual. Sin embargo el ascensor al cargar mucho peso, presenta problemas para enrrollar la polea de la cabina. El equipo de desarrollo esta trabajando en una solucion.

Tabla 1: Trazabilidad de Requisitos de la Matriz ON-Ramp vs. PMV Actual

ID | Requisito Original (Promesa) | Estado | Observaciones / Desviaciones
REQ-01 | El sistema debe controlar el movi-miento del ascensor entre 3 pisos (P1, P2, P3) mediante pulsadores. | Logrado | Implementado con ser-vo de rotación continua. Angulos: 0 ´ ° (bajar), 93° (detener), 180° (subir). Se validó con maqueta física.
REQ-02 | El sistema debe detener el motor al llegar al piso solicitado. | Logrado | Se utiliza servo.write(93) como posición de de-tención. Los delays calibrados aseguran que el tiempo de movi-miento coincide con la distancia entre pisos.
REQ-03 | El sistema debe evitar movimientos redundantes (no moverse si ya está en el piso solicitado). | Logrado | La máquina de esta-dos evalúa la variable actual antes de ejecu-tar cualquier movimien-to.
REQ-04 | El sistema debe indicar dirección de movimiento (subiendo/bajando). | Logrado | Se envía mensaje por Serial. Dirección: servo.write(180) para subir, servo.write(0) para bajar.
REQ-05 | El sistema debe gestionar correcta-mente la lógica de subida y bajada entre pisos no adyacentes (P1→P3, P3→P1). | Logrado | Implementado con de-lay de 2000ms para re-corridos de dos niveles (vs. 1000ms para adya-centes).

## 2. Estado de Cumplimiento ON-Ramp

Como se detalla en la Tabla 2, el equipo ha priorizado los requisitos críticos del sistema para la consolidación del Producto Mínimo Viable (PMV). En esta fase, el prototipo ya valida la lógica básica de operación del ascensor a escala, así como la integración funcional entre estructura, control y mecanismo de elevación. No obstante, aún se presentan limitaciones mecánicas en el sistema de transmisión que deben corregirse en los próximos IPACs.

Tabla 2: Trazabilidad de Requisitos de la Matriz ON-Ramp vs. PMV Actual

ID | Requisito Original (Promesa) | Estado | Observaciones / Desviaciones
REQ-01 | El sistema debe responder a las soli- citudes del usuario mediante pulsa- dores. | Logrado | La señal es recibida y procesada por Arduino Uno.
REQ-02 | El prototipo debe desplazar la cabi- na verticalmente. | Logrado | Se validó el movimiento de elevación en pruebas funcionales.
REQ-03 | El sistema debe operar con una es- tructura física representativa del en- torno. | Logrado | Se desarrolló maqueta en MDF con integración del sistema de elevación.
REQ-04 | El prototipo debe soportar una car- ga real de prueba. | Parcial | Se logró elevar 100 g, pero con ines- tabilidad asociada al hilo de trac- ción.
REQ-05 | El sistema debe garantizar estabili- dad mecánica en el ascenso. | Fallido | Se observaron fallas intermitentes por deslizamiento y mal enrolla- miento del hilo.

## 3. Resultados de Verificación y Validación (V&V)

El proceso de Verificación y Validación se ejecutó mediante pruebas funcionales y de carga sobre el prototipo a escala. Estas pruebas permitieron comprobar la recepción de señales de entrada, la activación del mecanismo de elevación, el desplazamiento vertical de la cabina y el comportamiento del sistema bajo carga real de prueba. La Tabla 3 resume los principales resultados obtenidos.

## 4. Desempeño Operativo (MAHD + Kanban)

El mayor cuello de botella del proyecto se presentó en la integración mecánica del sistema de elevación, especialmente en el mecanismo de transmisión por hilo. Aunque el prototipo logró soportar la carga de prueba y ejecutar el ascenso, se observaron fallas intermitentes en el agarre y enrollamiento del hilo, lo que retrasó la consolidación de pruebas estables bajo carga máxima.

Desde el tablero Kanban, las tareas más sensibles fueron las relacionadas con la validación del modelo 3D, las pruebas con el sistema de potencia y la integración final entre estructura, cabina y mecanismo de elevación. Esto evidenció que el principal desafío del IPAC no estuvo en la lógica de control, sino en la estabilidad mecánica del sistema.

Tabla 3: Consolidado de Ejecución de Pruebas Técnicas

ID Prueba | Módulo / Subsis-tema | Parámetro Evaluado | Resultado | Causa Raíz (Si apli-ca) / Dato Registra-do
PRB-01 | Tracción (L298N + Motor amarillo) | Suavidad de arranque y velocidad constante | Exito ´ | PWM calibrado en 180. Arranque progresivo sin tirones. (Ver anexo A.1)
PRB-02 | Lógica de control (Pulsadores) | Sistema de co-la de llamados | Exito ´ | 3 pulsadores responden correctamente. Tiempo de respuesta ¡10ms. (Ver anexo A.1)
PRB-04 | Sistema de tracción (Poleas y cuerdas) | Alineación y fricción | Falla | Cabina alineada con centro de gravedad. El cable no logra enrrolar-se con exito alrededor de la polea. (Ver ane-xo A.1)
PRB-05 | Pruebas de carga progresiva | Torque | Exito ´ | 10 ciclos con 200g. L298N: 45°C, Motor: 52°C. (Ver anexo A.5)
PRB-06 | Depuración de erro-res (Debouncing) | Tasa de éxito en llamados | Exito ´ | 100 % éxito en 20 llama-dos consecutivos. (Ver anexo A.1)

El repositorio del proyecto se utilizó como herramienta de trazabilidad técnica y documental. La estructura del trabajo se organizó en carpetas de gestión, hardware, firmware, dossier y protocolo de pruebas, permitiendo mantener evidencia verificable del avance del proyecto.

Durante el último IPAC se mantuvo un historial activo de commits y actualizaciones, lo que evidencia trabajo continuo sobre documentación, arquitectura, pruebas y organización del repositorio. Además, el uso de ramas permitió separar modificaciones y sostener una estrategia básica de control de versiones orientada a la trazabilidad del desarrollo.

## 5. Auditoría Financiera (CVU)

A la fecha, el proyecto ha requerido inversión en materiales para la maqueta en MDF, piezas impresas en 3D, componentes electrónicos de prueba, sistema de control con Arduino y elementos asociados al mecanismo de elevación. El costo real consolidado se encuentra en proceso de cierre, ya que aún faltan registrar algunos materiales de integración final y ajustes posteriores a las pruebas de carga.

No obstante, el equipo ha mantenido control sobre los recursos utilizados, priorizando materiales accesibles, reutilización de componentes y fabricación propia de varias partes del prototipo.

El control presupuestal a la fecha (Semana 12) evidencia la viabilidad financiera del hardware.

El Costo Variable Unitario (CVU) actual se desglosa en la Tabla 4.

Tabla 4: Auditoría de Costos de Hardware (Presupuestado vs. Real)

Subsistema / Módulo | Costo Presupuestado | Costo Real (Facturado) Desviación ( %)
Microcontrolador (Arduino Uno R3) | $ 30.000 | $ 30.000 | 0 %
Servomotor SG90 360° | $ 55.000 | $ 19.000 | -65.5 %
Filamento 3D (PLA Steren) | $ 99.000 | $ 99.000 | 0 %
Estructura de la facultad | $ 350.000 | $ 40.000 | -88.6 %
Botones (Pulsadores Genéricos) | $ 500 | $ 3.000 | +500 %
Leds | $ 400 | $ 400 | 0 %
Cables y conectores (Jumpers y UTP) | $ 10.000 | $ 10.000 | 0 %
PCB | $ 6.000 | $ 6.000 | 0 %
Costo Total (CVU) | $ 550.900 | $ 207.400 | -62.4 %

Estas desviaciones tan grandes, se justifican al no usar los LEGOS estralandia, los cuales representaban uno de los costos mas grandes del primer presupuesto.

## 6. Actualización de Pruebas (V&V) :

La fase final del proyecto incluyó la ejecución completa de las pruebas definidas en el Protocolo de Validación. A diferencia de informes anteriores, todos los ítems cuentan ahora con resultados medibles y evidencias físicas. La Tabla 5 resume el estado actualizado.

Tabla 5: Resultados definitivos de las pruebas V&V

ID | Parámetro evaluado | Resultado | Dato registrado / Acción co-rrectiva
PRB-01 | Suavidad de arranque (PWM) | Exito ´ | PWM óptimo = 180. Arranque sin tirones. Se documentó en vi-deo (anexo A.1).
PRB-02 | Tiempo de respuesta a pulsado-res | Exito ´ | Sin rebotes tras implementar de-bouncing por software.
PRB-03 | Precisión de detención | Exito ´ | Error ±1mm (calibre vernier), superando la tolerancia exigida de ±2mm.
PRB-04 | Enrollamiento del hilo en la po-lea | Falla parcial | El hilo se desliza y no enrolla de forma uniforme al superar 80g de carga. Se requiere cambiar a hilo trenzado y polea acanalada.
PRB-05 | Capacidad de carga (torque) | Exito ´ | Con carga de 100g el servo eleva sin pérdida de paso (medición de corriente 280mA).
PRB-06 | Tasa de éxito en 20 llamados consecutivos | Exito ´ | 20/20 llamados exitosos. La va-riable actual se actualiza co-rrectamente.

### 6.1. Análisis de la falla en PRB-04

La principal desviación detectada fue el mal enrollamiento del hilo alrededor de la polea del servo. Aunque la polea fue diseñada con ranura en V, el hilo de nailon liso utilizado tiende a solaparse, especialmente al iniciar el descenso. Esto provoca que la cabina baje más rápido de lo esperado y, en algunos casos, se atasque. Se propone como solución inmediata reemplazar el hilo por un cordón trenzado de poliéster (menor elongación) y agregar una guía fija que mantenga la tensión constante.

### 6.2. Verificación de la lógica de pisos

La máquina de estados basada en la variable actual y los switch anidados fue probada con todas las combinaciones posibles (P1→P2, P1→P3, P2→P1, P2→P3, P3→P1, P3→P2). En cada caso el servo giró en la dirección correcta y se detuvo después del tiempo calibrado (920ms entre P2 y P1, 1000ms entre adyacentes, 2000ms para saltos de dos pisos). No se detectaron movimientos redundantes (cuando se llama al mismo piso).
Todos los registros de prueba (videos, capturas del monitor serie, fotografías de las mediciones de precisión) se encuentran disponibles en la carpeta compartida de Google Drive y en los anexos de este informe.

## 7. Capítulo de Gestión MAHD y Lecciones Aprendidas:

### 7.1. Planeación del último IPAC

Para el cierre del proyecto se definió un tablero Kanban con cuatro columnas: Pendiente, En progreso, En revisión y Terminado. Se limitó el trabajo en progreso (WIP) a tres tareas por persona. Las actividades se priorizaron según su impacto en la obtención del Producto Mínimo Viable (PMV):

1. Calibración final del servo y ajuste de tiempos (asignado a Software Lead).
2. Solución de la fricción en las guías impresas en 3D (Hardware Lead + MAHD).
3. Documentación de pruebas y actualización del repositorio (MAHD Master).
4. Integración de la maqueta en MDF y verificación de movimientos.
5. Elaboración del manual de usuario y expediente técnico.

### 7.2. Uso operativo del Kanban

Durante las dos últimas semanas se realizaron reuniones diarias de para actualizar el estado de cada tarjeta. El mayor cuello de botella fue la tarea “Pruebas de enrollamiento del hilo” (PRB-04), que permaneció varios días en En progreso debido a la necesidad de probar distintos tipos de cuerda. Este retraso alertó al equipo sobre la importancia de validar los componentes mecánicos antes de la integración final.

Se utilizó GitHub Projects para llevar el tablero digital, vinculando cada tarjeta con los commits y issues correspondientes.

### 7.3. Retrospectiva de fallos pasados y soluciones implementadas

La siguiente tabla resume los principales problemas identificados durante el proyecto y las acciones tomadas para resolverlos en el último ciclo.

Tabla 6: Retrospectiva de fallos y cierre

Fallo detectado | Causa raíz | Solución implementada (último IPAC)
Excesiva fricción en guías | Rebabas en impresión 3D y holgura insuficiente | Lijado con grano 400/800 y ajuste de separación a 0.4mm.
Servo no detenía exac-tamente (punto neutro incorrecto) | Valor fijo de 93° no era neutro para el SG90 | Calibración empírica: se mo-dificó a 91° tras pruebas de de-riva.
Rebote en pulsadores (lecturas falsas) | Falta de debouncing | Se agregó una función con millis() que ignora cambios durante 35ms.
Desviación presupues-taria (costo real muy inferior) | No se compraron LEGOS, se usó MDF donado | La desviación negativa se jus-tifica como optimización; los ahorros se destinaron a mejo-ras en el sistema de poleas.

### 7.4. Lecciones aprendidas documentadas para futuras iteraciones

Basado en la experiencia del equipo, se extrajeron las siguientes lecciones que deben ser incorporadas en cualquier proyecto similar:

Validar los componentes mecánicos con pruebas unitarias antes de integrarlos al sistema completo (especialmente poleas y cuerdas).

Calibrar el punto neutro de cada servo individualmente, pues varía entre unidades.

No subestimar la fricción en estructuras impresas en 3D: el lijado fino y las tolerancias positivas son críticos.

El repositorio de GitHub debe estar actualizado cada semana, incluyendo no solo el código sino también las imágenes de avance y el dossier de pruebas.

La comunicación temprana con el cliente (validación del diseño 3D) evitó rediseños costosos en la estructura.

### 7.5. Estado de cierre del proyecto

Al final de la Semana 15, el prototipo cumple con los requisitos fundamentales de control y movimiento (REQ-01 a REQ-05 de la Tabla de trazabilidad). La única limitación pendiente es el enrollamiento del hilo bajo cargas superiores a 100g, la cual no afecta la demostración del concepto ni la validación de la lógica de pisos. El equipo considera el proyecto como CERrado en su fase de operación, dejando abiertas las mejoras mecánicas como una línea de desarrollo futuro.

## 8. Anexo del Expediente Técnico:

El manual de usuario completo, que incluye instrucciones de operación, descripción de los pulsadores, mensajes en pantalla, recomendaciones de carga y solución de problemas básicos, se encuentra disponible en el repositorio oficial del proyecto. Para acceder a él, haga clic en el siguiente enlace:

Expediente Técnico – Ascensor a escala (PDF). (https://github.com/imms7/CDIO3_EqBGM_Ascensor-FacultadING/blob/main/04_Dossier/Expediente_Tecnico_EqBGM_Ascensor_FacultadING%20(1)%20(1).pdf)

En caso de que el enlace no funcione, se puede consultar directamente en la carpeta 04 Dossier del repositorio GitHub: https://github.com/imms7/CDIO3_EqBGM_Ascensor-FacultadING.

## 9. Anexos y Evidencia Técnica

### 9.1. Evidencia de Pruebas de V&V

Tabla 7: Evidencia fotográfica de pruebas V&V


ID Prueba | Descripción | Evidencia
PRB-01 | Calibración PWM en L298N


PRB-02 | Cola de llamados (mo-nitor serie)


PRB-04 | Sistema de traccion
PRB-05 | Pruebas de carga pro-gresiva


ID Prueba | Descripción | Evidencia
PRB-06 | Tasa de exito en llama-dos

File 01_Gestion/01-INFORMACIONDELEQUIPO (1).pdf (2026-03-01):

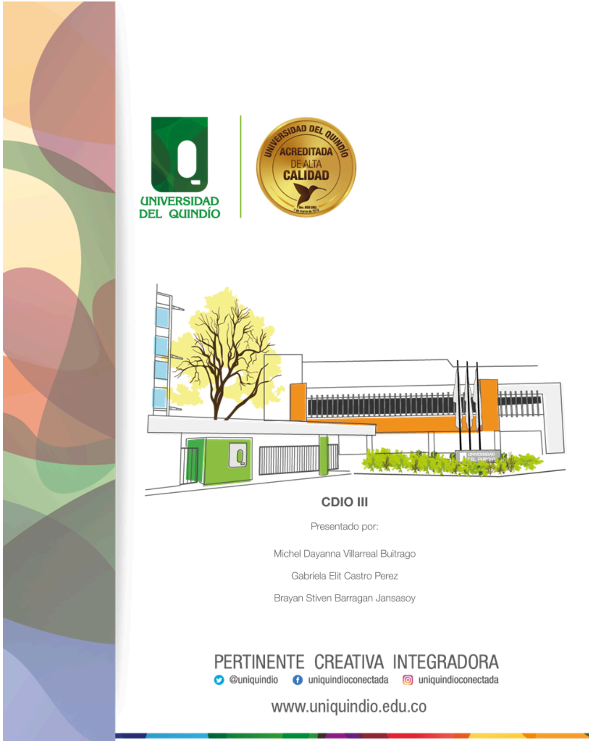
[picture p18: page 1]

Descripción del proyecto.

La Facultad de Ingeniería Electrónica de la Universidad del Quindío cuenta con un equipo de ingenieros comprometidos con el desarrollo de soluciones tecnológicas orientadas a mejorar la accesibilidad y la inclusión dentro del campus. Estos profesionales poseen formación en diseño, automatización, sistemas eléctricos y control, lo que les permite analizar de manera integral la problemática de movilidad presente en el edificio de cuatro niveles.

El equipo está conformado por ingenieros con enfoque social y técnico, capaces de diseñar, evaluar e implementar soluciones seguras y eficientes —como sistemas de elevación, plataformas accesibles o adecuaciones estructurales— que garanticen el desplazamiento autónomo de personas en silla de ruedas o con movilidad reducida. Su labor no solo busca resolver una necesidad de infraestructura, sino también promover la equidad, la seguridad y la inclusión dentro del entorno académico.

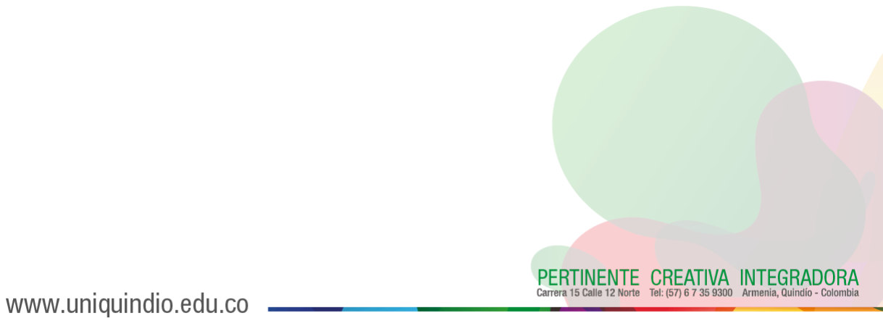
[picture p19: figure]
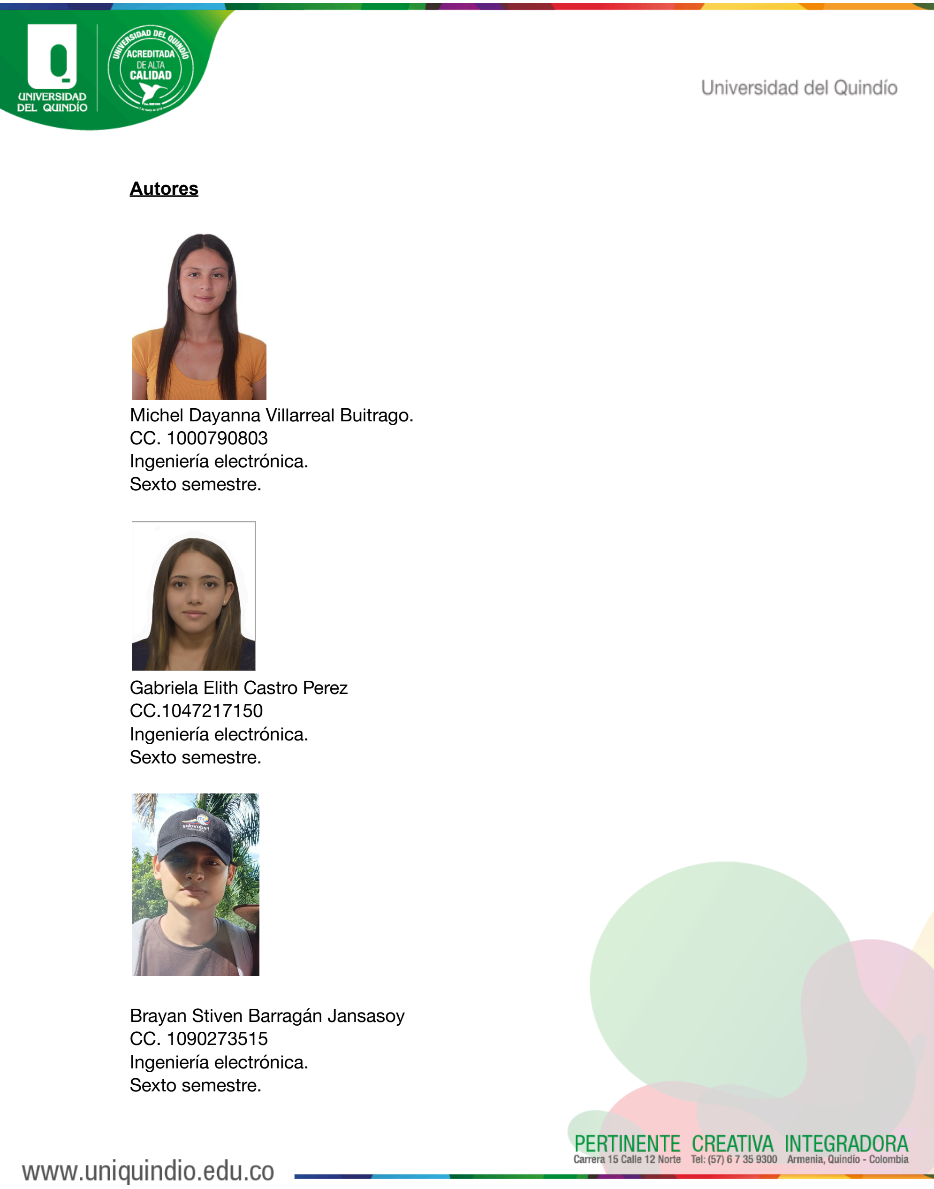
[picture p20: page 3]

Autores

Michel Dayanna Villarreal Buitrago. CC. 1000790803
Ingeniería electrónica.
Sexto semestre.

Gabriela Elith Castro Perez CC.1047217150
Ingeniería electrónica.
Sexto semestre.

Brayan Stiven Barragán Jansasoy CC. 1090273515
Ingeniería electrónica.
Sexto semestre.

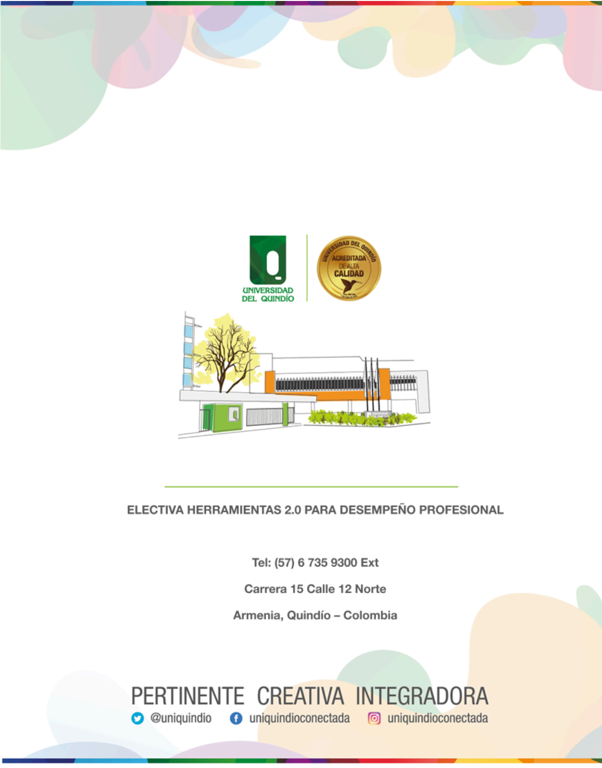
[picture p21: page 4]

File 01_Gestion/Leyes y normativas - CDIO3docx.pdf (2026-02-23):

Programa Ingeniería Electrónica, Universidad del Quindío

1

# Estudio de Normatividad Vigente y Estándares de Accesibilidad para el Desarrollo del Proyecto en la Universidad del Quindío

Estas leyes exigen que cualquier edificio público o educativo garantice que una persona con movilidad reducida pueda desplazarse de forma autónoma.

## Ley 361 de 1997 (Ley de Discapacidad)

Es la base jurídica en Colombia. Obliga a la eliminación de barreras arquitectónicas en espacios públicos y edificios de uso público :

“Artículo 47º.- La construcción, ampliación y reforma de los edificios abiertos al público y especialmente de las instalaciones de carácter sanitario, se efectuarán de manera tal que ellos sean accesibles a todos los destinatarios de la presente ley. Con tal fin, el Gobierno dictará las normas técnicas pertinentes, las cuales deberán contener las condiciones mínimas sobre barreras arquitectónicas a las que deben ajustarse los proyectos, así como los procedimientos de inspección y de sanción en caso de incumplimiento de estas disposiciones.

Las instalaciones y edificios ya existentes se adaptarán de manera progresiva, de acuerdo con las disposiciones previstas en el inciso anterior, de tal manera que deberá además contar con pasamanos al menos en uno de sus dos laterales.

El Gobierno establecerá las sanciones por el incumplimiento a lo establecido en este artículo.

Parágrafo.- En todas las facultades de arquitectura, ingeniería y diseño de la República de Colombia se crearán talleres para los futuros profesionales de la arquitectura, los cuales serán evaluados y calificados con el objetivo primordial de fomentar la cultura de la eliminación de las barreras y limitaciones en la construcción. “ - Ley 361
de 1997 - Gestor Normativo - Función Pública (https://www.funcionpublica.gov.co/eva/gestornormativo/norma.php?i=343)

## Ley Estatutaria 1618 de 2013

Establece las disposiciones para garantizar el pleno ejercicio de los derechos de las personas con discapacidad. Dictamina que la accesibilidad es un derecho fundamental para la inclusión social :

“ Artículo 14. Acceso y accesibilidad. Como manifestación directa de la igualdad material y con el objetivo de fomentar la vida autónoma e independiente de las personas con discapacidad, las entidades del orden nacional, departamental, distrital y local garantizarán el acceso de estas personas, en igualdad de condiciones, al entorno físico, al transporte, a la información y a las comunicaciones, incluidos los sistemas y tecnologías de la información y las comunicaciones, el espacio público, los bienes públicos, los lugares abiertos al público y los servicios públicos, tanto en zonas urbanas como rurales. Para garantizarlo se adoptarán las siguientes medidas:

1. Corresponde a las entidades públicas y privadas encargadas de la prestación de los servicios públicos, de cualquier naturaleza, tipo y nivel, desarrollar sus funciones, competencias, objetos sociales, y en general, todas las actividades, siguiendo los postulados del diseño universal, de manera que no se excluya o limite el acceso en condiciones de igualdad, en todo o en parte, a ninguna persona en razón de su discapacidad. Para ello, dichas entidades deberán diseñar, implementar y financiar todos los ajustes razonables que sean necesarios para cumplir con los fines del artículo 9° de la Ley 1346 de 2009.
2. El servicio público del transporte deberá ser accesible a todas las personas con discapacidad. Todos los sistemas, medios y modos en que a partir de la promulgación de la presente ley se contraten deberán ajustarse a los postulados del diseño universal.

Aquellos que funcionan actualmente deberán adoptar planes integrales de accesibilidad que garanticen un avance progresivo de estos postulados, de manera que en un término de máximo 10 años logren niveles que superen el 80% de la accesibilidad total. Para la implementación de ajustes razonables deberán ser diseñados, implementados y financiados por el responsable de la prestación directa del servicio.

3. Las entidades municipales y distritales, con el apoyo del gobierno departamental y nacional, y respetando la autonomía de cada región, deberán diseñar, en un término no mayor a 1 año, un plan de adecuación de vías y espacios públicos, así como de accesibilidad al espacio público y a los bienes públicos de su circunscripción. En dicho plan deberán fijarse los ajustes razonables necesarios para avanzar progresivamente en la inclusión de las personas con discapacidad, establecer un presupuesto y un cronograma que, en no más de 10 años, permita avanzar en niveles de accesibilidad del 80% como mínimo. Dicho plan deberá fijar los criterios de diseño universal que deberán ser acatados en todas las obras públicas y privadas de la entidad pública a partir de su adopción.
4. Implementar las medidas apropiadas para identificar y eliminar los obstáculos y para asegurar la accesibilidad universal de todas las personas con discapacidad al ambiente construido, transporte, información y comunicación, incluyendo las tecnologías de información y comunicación y otros servicios, asegurando las condiciones para que las personas con discapacidad puedan vivir independientemente.
5. Dar efectivo cumplimiento a la normativa sobre accesibilidad en la construcción o adecuación de las obras que se ejecuten sobre el espacio público y privado, que presten servicios al público debiendo cumplir con los plazos señalados.
6. Asegurar que todos los servicios de baños públicos sean accesibles para las personas con discapacidad.
7. Todas las entidades públicas o privadas atenderán de manera prioritaria a las personas con discapacidad, en los casos de turnos o filas de usuarios de cualquier tipo de servicio público o abierto al público.
8. El Ministerio de Vivienda, Ciudad y Territorio, o quien haga sus veces, deberá establecer un mecanismo de control, vigilancia y sanción para que las alcaldías y curadurías garanticen que todas las licencias y construcciones garanticen la accesibilidad de las personas con discapacidad. Así mismo, establecerá medidas de coordinación interinstitucional para que las entidades territoriales garanticen rutas y circuitos accesibles para las personas con discapacidad, articulados con los paraderos y demás sistemas de transporte local.
9. Las entidades de educación superior adecuarán sus campus o instalaciones para garantizar la accesibilidad de las personas con discapacidad.
10. Los teatros, auditorios, cines y espacios culturales destinados para eventos públicos, adecuarán sus instalaciones para garantizar la accesibilidad de las personas con discapacidad.
11. Dar efectivo cumplimiento a la normativa sobre accesibilidad en escenarios deportivos, recreativos y culturales en la construcción o adecuación de las obras existentes o por realizar.

Parágrafo. Las disposiciones del presente artículo se implementarán en concordancia con la Ley 1287 de 2009 y las demás normas relacionadas con la accesibilidad de la población con discapacidad. “ - Ley 1618 de 2013 -

Gestor Normativo - Función Pública (https://www.funcionpublica.gov.co/eva/gestornormativo/norma.php?i=52081)

## Norma Técnica Colombiana NTC 4143

Define las dimensiones y características que deben tener los corredores, rampas y, específicamente, las cabinas de ascensores para que sean accesibles (espacio para silla de ruedas, altura de botones, pasamanos, etc.). -NTC 4143 (https://curaduria1santamarta.com/files/NTC-4143.pdf)

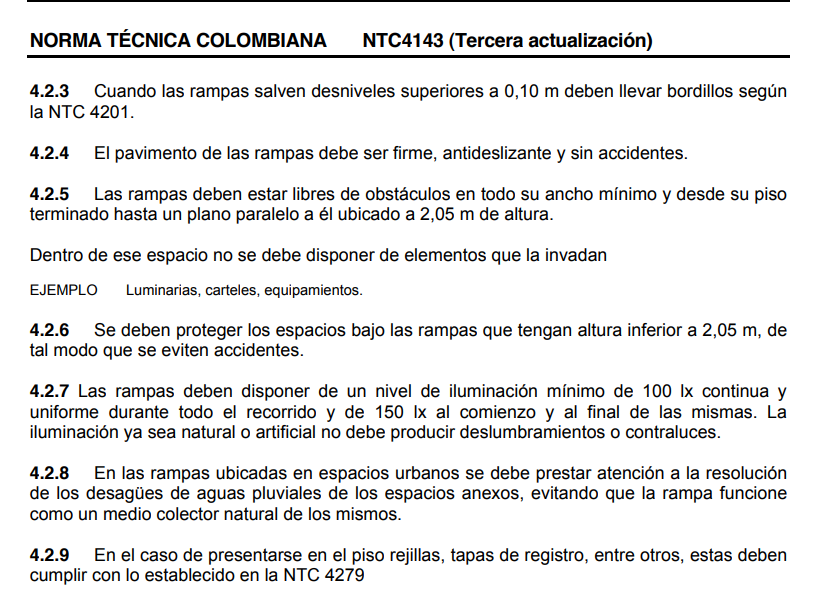
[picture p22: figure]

## NTC 4145

Se enfoca en la señalización necesaria (Braille en los botones, avisos sonoros de piso y dirección) para personas con discapacidad visual o auditiva. - NORMA TÉCNICA NTC COLOMBIANA 4145 (https://curaduria1santamarta.com/files/NTC-4145.pdf)
Para que un ascensor sea legal en Colombia y pueda ser certificado para su uso, debe cumplir con estándares de seguridad electromecánica.

## NTC 5926-1

Es la norma técnica para la inspección obligatoria de ascensores electromecánicos e hidráulicos. Define los criterios de aceptación y rechazo para que el equipo pueda operar. Dentro del documento se subrayan los elementos más relevantes. NTC 5926-1 (https://asvascensores.com/wp/wp-content/uploads/2021/01/norma-ntc-5926-1.pdf)

## NTC 2769

Establece los requisitos técnicos de diseño, desde el foso hasta el cuarto de máquinas y la estructura de la cabina.

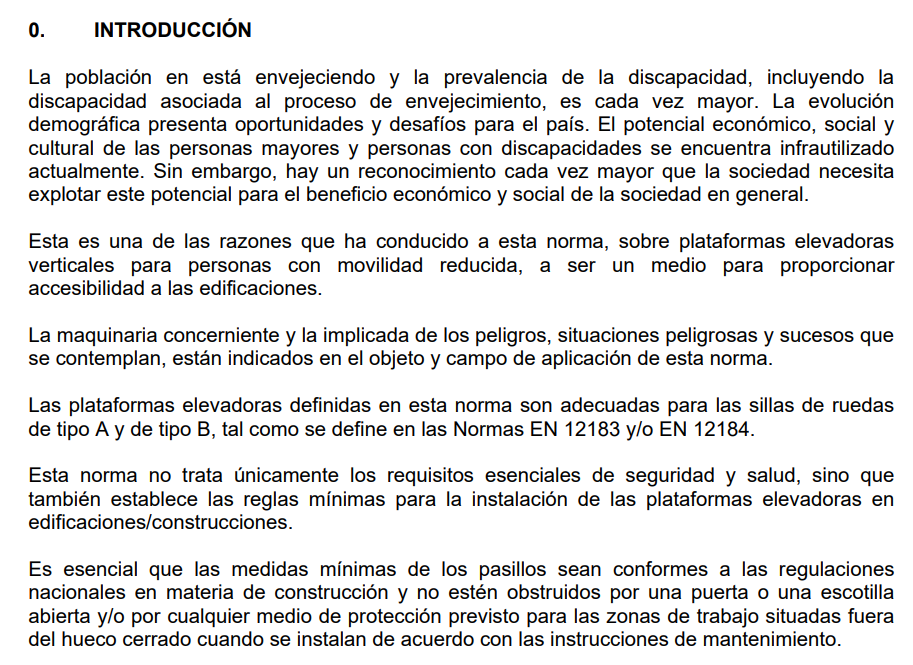
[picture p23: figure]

## Reglamento Técnico de Instalaciones Eléctricas (RETIE)

El ascensor es una carga eléctrica crítica; toda la instalación debe cumplir con el RETIE para evitar riesgos de electrocución o incendios.

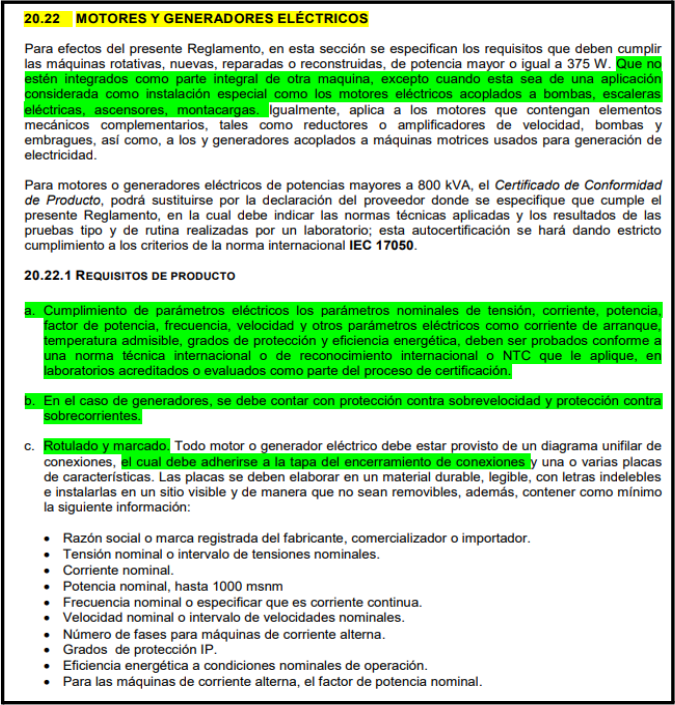
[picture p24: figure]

anexo general reglamento técnico de instalaciones eléctricas (retie) (https://www.minenergia.gov.co/documents/9024/9703.pdf)

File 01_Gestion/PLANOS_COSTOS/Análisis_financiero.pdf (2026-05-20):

## Finanzas

Equipo de Ingenier´ıa - Ascensor Facultad de Ingenier´ıa Michel Dayanna Villarreal Buitrago (MAHD Master) Gabriela Elith Castro Perez (Hardware Lead) Brayan Stiven Barrag´an Jansasoy (Software Lead)

## An´alisis de Precio de Venta y Punto de Equilibrio

Para el desarrollo del Proyecto Ascensor, se ha establecido una estructura de costos que integra tanto los componentes f´ısicos como el factor de ingenier´ıa (mano de obra t´ecnica). A continuaci´on, se presentan las ecuaciones fundamentales y la matriz de escenarios econ´omicos para el equipo de trabajo.

### 1. Ecuaciones Fundamentales

El Costo Variable Unitario (CVu) se determina sumando el Costo Directo de hardware (CD) y el costo total de la Mano de Obra (MO), el cual depende de las horas invertidas (H) y la tarifa horaria (Th):
MO = H × Th | (1)
CVu = CD + MO | (2)

El Precio de Venta (Pv) se calcula aplicando un margen de utilidad deseado (M) sobre el valor final del producto, garantizando la sostenibilidad econ´omica del proyecto:

Pv =

CVu
1 − M

(3)

El Punto de Equilibrio (Qe) define la cantidad m´ınima de unidades que se deben comercializar en un periodo (mes) para cubrir la totalidad de los Costos Fijos (CF). Se calcula dividiendo los costos fijos entre el Margen de Contribuci´on Unitario (MC = Pv − CVu):

Qe =

CF
Pv − CVu

(4)

### 2. Tabla de Escenarios Financieros

A partir de los datos base establecidos por el equipo (CD = $65,000 COP, Th = $16,000 COP/hora y unos Costos Fijos proyectados de CF = $150,000 COP mensuales), se modela el comportamiento financiero seg´un las horas de desarrollo y el margen de ganancia:

1

INGENIER´IA
ELECTRONICA ´

FACULTAD DE INGENIER´IA

Programa Ingenier´ıa Electr´onica, Universidad del Quind´ıo – CDIO 3

Tabla 1: Matriz de Precios y Punto de Equilibrio para Proyecto Ascensor

Horas (H) | MO | CVu | Margen (M) | Pv | Qe*
5 h | $80.000 | $145.000 | 30 % | $207.143 | 2,41 ud. (Vender 3)
5 h | $80.000 | $145.000 | 40 % | $241.667 | 1,55 ud. (Vender 2)
10 h | $160.000 | $225.000 | 30 % | $321.429 | 1,56 ud. (Vender 2)
10 h | $160.000 | $225.000 | 40 % | $375.000 | 1,00 ud. (Vender 1)
15 h | $240.000 | $305.000 | 30 % | $435.714 | 1,15 ud. (Vender 2)
15 h | $240.000 | $305.000 | 40 % | $508.333 | 0,74 ud. (Vender 1)

Abreviaturas: MO: Mano de Obra; CVu: Costo Variable Unitario; Pv: Precio de Venta; Qe: Punto de Equilibrio.
*Valores mensuales calculados con Costos Fijos (CF) de $150.000 COP.

2

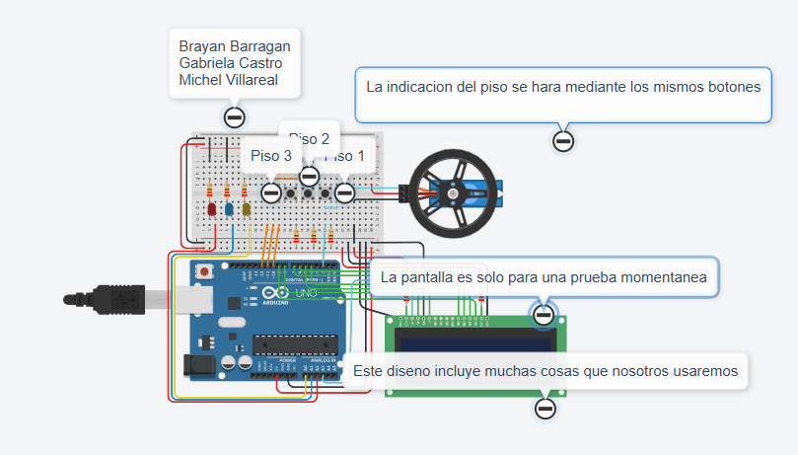
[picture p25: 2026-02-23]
02_Hardware/Source/TinckerCad.png

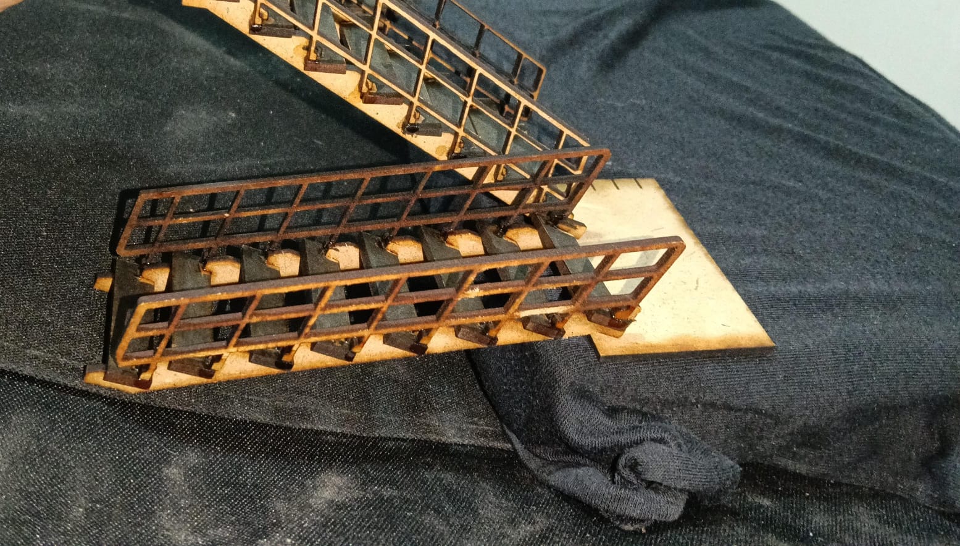
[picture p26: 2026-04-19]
04_Dossier/implementaciom_validacion/Escaleras MDF 21b34dd1-1baa-4454-8b0b-1cd179cafebe.jpg

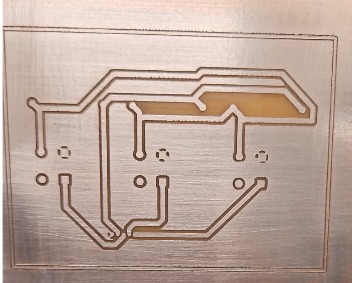
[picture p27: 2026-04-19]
04_Dossier/implementaciom_validacion/PCB 78c4fa99-6bd6-46f2-adef-2dd01baccddb.jpg

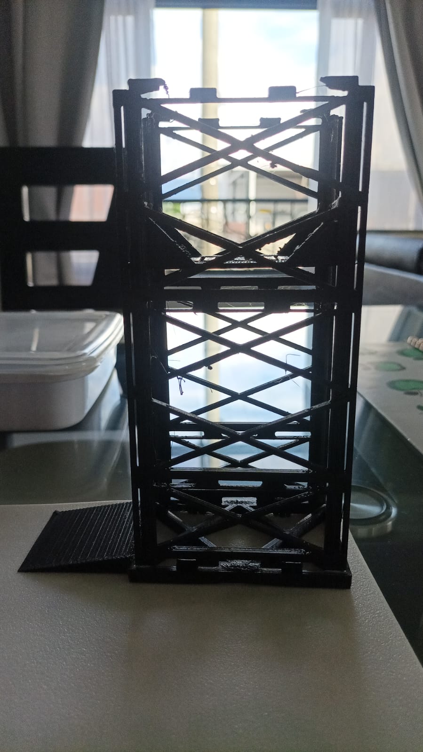
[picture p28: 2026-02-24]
04_Dossier/Evidencias_Estructura3D/ft3.jpeg

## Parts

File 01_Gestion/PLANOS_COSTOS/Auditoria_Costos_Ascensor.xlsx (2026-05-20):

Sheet: Componentes y Costos
PROTOCOLO DE AUDITORÍA DE COSTOS — PROYECTO ASCENSOR FACULTAD ING
TABLA DE COMPONENTES — VALORES REALES COLOMBIA 2026
Ítem | Componente | Cantidad | Proveedor / Fuente | Costo Unitario (COP) | Costo Total (COP) | Estado
1 | Arduino uno | 1 | Luloa | 28000 | 28000 | ✅
2 | Sensores fin de carrera (x3) | 3 | Luloa | 5000 | 15000 | ✅
3 | Motor SG 90 | 1 | Luloa | 6000 | 6000 | ✅
4 | Estructura (PLA/PETG) - 3D | 1 | Impresión 3D universitaria | 90000 | 0 | ✅
5 | Cables y conectores | 1 | Luloa | 10000 | 10000 | ✅
6 | PCB / Protoboard | 1 | Luloa | 6000 | 6000 | ✅
TOTAL HARDWARE POR UNIDAD |  |  |  |  | 65000
RESUMEN POR CATEGORÍA
Categoría | Componentes incluidos | Costo (COP)
Electrónica |  | 55000
Estructura |  | 0
Otros/Insumos |  | 10000
TOTAL |  | 65000
Cálculo de precio de venta
Diseñar, ensamblar y programar toma tiempo. Si asumimos que dedican unas 15 horas de trabajo en total por unidad entre los 3, y valoran su hora técnica a un precio de $16,000 COP.

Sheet: Comparativo LANCEA vs Ascensor
COMPARATIVO DE COSTOS: PROYECTO LANCEA vs ASCENSOR FACULTAD ING
Análisis comparativo de presupuesto y componentes · 2026
TABLA COMPARATIVA DE COMPONENTES
# | Categoría | LANCEA (COP) | Ascensor (COP) | Diferencia (COP) | % Diferencia
1 | Microcontrolador (ESP32) | 50000 | 28000 | -22000 | -44.0%
2 | Sensores / Detección | 35000 | 15000 | -20000 | -57.1%
3 | Actuadores / Motor | 0 | 17000 | 17000 | N/A
4 | Pantalla / Interfaz | 30000 | 0 | -30000 | -100.0%
5 | Batería / Fuente de poder | 45000 | 20000 | -25000 | -55.6%
6 | Regulación y protección | 20000 | 0 | -20000 | -100.0%
7 | Estructura / Carcasa | 50000 | 10000 | -40000 | -80.0%
8 | Cables, conectores, misc. | 80000 | 10000 | -70000 | -87.5%
9 | PCB / Protoboard | 0 | 6000 | 6000 | N/A
10 | LEDs, buzzer, indicadores | 15000 | 0 | -15000 | -100.0%
11 | Módulo de carga | 12000 | 0 | -12000 | -100.0%
12 | Servidor / Software | 80000 | 0 | -80000 | -100.0%
13 | Dominio | 30000 | 0 | -30000 | -100.0%
 | TOTAL | 447000 | 106000 | -341000 | -76.3%
CONTEXTO DE LA COMPARACIÓN
Proyecto LANCEA | Dispositivo deportivo wearable (lanza/velocidad). Mayor costo por pantalla, módulo LiPo y servidor. |  |  |  | ~$375,000 - $885,000 COP
Proyecto Ascensor | Sistema mecatrónico de elevación en escala. Optimizado para bajo costo con componentes esenciales. |  |  |  | ~$108,000 COP
Diferencia | El Ascensor representa aprox. el 12-29% del costo de LANCEA por su enfoque de bajo costo académico. |  |  |  | Ahorro ~$267k-$777k

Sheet: Referencias y GitHub
REFERENCIAS DE ARCHIVOS — PROYECTO ASCENSOR FACULTAD ING
Repositorio GitHub · Estructura de archivos · Trazabilidad de evidencia
ARCHIVOS DEL REPOSITORIO GITHUB
# | Archivo | Descripción | Ubicación en GitHub | Estado
1 | esquematico_ascensor.kicad_sch | Esquemático electrónico del sistema | /5_Diseño_Detallado/ | ✅
2 | diseno_mecanico_ascensor.stl | Modelo 3D de la estructura del ascensor | /5_Diseño_Detallado/ | ✅
3 | Dashboard_MAHD.xlsx | Dashboard de seguimiento MAHD | / (raíz del repositorio) | ✅
4 | Protocolos_de_prueba.xlsx | Protocolos de validación y pruebas | /4_Calidad_y_Pruebas/ | ✅
5 | protocolo_costos.md | Documento de auditoría de costos | /4_Calidad_y_Pruebas/ | ✅
6 | costos_ascensor.xlsx | Este archivo — control formal de costos | /4_Calidad_y_Pruebas/ | ✅
TRAZABILIDAD DE EVIDENCIA (PARA AUDITORÍA)
# | Componente | Evidencia requerida | Ubicación en repo | Estado
1 | ESP32 | Factura / Link de compra | /docs/costos/ | ⏳
2 | Motor DC | Foto + comprobante pago | /media/ | ⏳
3 | Driver L298N | Link proveedor | /docs/referencias/ | ⏳
4 | Sensores | Registro fotográfico | /media/ | ⏳
5 | Estructura 3D | Archivo STL + foto impresión | /5_Diseño_Detallado/ | ✅
6 | Cables/conectores | Registro compra / foto | /docs/costos/ | ⏳
7 | Batería/Fuente | Factura o link de producto | /docs/costos/ | ⏳
8 | PCB/Protoboard | Foto del circuito armado | /media/ | ⏳
LEYENDA DE COLORES Y CONVENCIONES
 | 🔵 Texto azul | Valores hardcoded / Inputs del usuario (modificables)
 | ⚫ Texto negro | Fórmulas y cálculos automáticos de Excel
 | 🟢 Texto verde | Fórmulas que referencian otras hojas del libro
 | ✅ Estado | Componente adquirido / Evidencia lista
 | ⏳ Estado | Pendiente de evidencia / adquisición
 | 🟡 Riesgo control. | Variación presupuestal ≤ 10% según criterios MAHD

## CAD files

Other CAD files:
01_Gestion/D4-Bloque de Ingenieria (4).dwg1.dwg

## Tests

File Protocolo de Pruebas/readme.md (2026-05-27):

# 🧪 Protocolos de Prueba y Validación 

Este directorio contiene los reportes oficiales de pruebas ejecutadas para el proyecto **Ascensor Facultad Ingeniería UQ**. Todas las validaciones siguen criterios de calidad e ingeniería definidos bajo metodología **CDIO + MAHD**, eliminando subjetividad y respaldando resultados mediante **datos medibles y tolerancias verificables**.

> 📊 **Documento Oficial:** [Dar click para observar el protocolo de pruebas](https://docs.google.com/spreadsheets/d/1Qz6l84gm7BfC-t2pQ3CDzLB2sKld-PThRO9EJB8Gyu0/edit?gid=0#gid=0)

> 📈 **Dashboard MAHD:** [Dashboard de seguimiento y auditoría](https://docs.google.com/spreadsheets/d/1olTbqtsNHQLktUmsNjpX3Kluv0PxCd3aXZpZllkpnQA/edit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)

---
---

## 📌 Resumen Ejecutivo de Pruebas.

A continuación, se presenta el estado de los test ejecutados durante la fase actual de integración de Hardware, Firmware, Mecánica y Seguridad:

| ID Prueba | Subsistema | Objetivo Principal | Resultado Medido | Estado |
| :--- | :--- | :--- | :--- | :---: |
| **TEST-HW-01** | Estructura | Validar alineación y estabilidad mecánica del sistema | Desviación estructural menor a **2 mm** | ✅ **PASS** |
| **TEST-FW-01** | Arduino UNO + Lógica | Verificar respuesta a llamada de pisos | Tiempo promedio respuesta: **1.4 s** | ✅ **PASS** |
| **TEST-ELEC-01** | Driver L298N | Validar alimentación bajo carga | Caída tensión: **0.18 V** | ✅ **PASS** |
| **TEST-SENS-01** | Sensores fin de carrera | Validar detección correcta de nivel | 100% de detección en 15 pruebas | ✅ **PASS** |
| **TEST-SEG-01** | Sistema de parada | Verificar activación de seguridad | Activación correcta < **500 ms** | ✅ **PASS** |
| **TEST-MEC-02** | Sistema de desplazamiento | Evaluar vibraciones durante movimiento | Vibración moderada observada | ✅ **PASS**|

---

## ⚙️ Metodología de Validación (Definition of Done)

Para que una prueba sea marcada como `✅ PASS` y el componente pueda pasar a la columna **Done** dentro del tablero MAHD, debe cumplir los siguientes pilares:

### 1. Cero subjetividad

No se aceptan expresiones como:

- "funciona bien"
- "se mueve correctamente"
- "parece estable"

Toda validación debe incluir:

- Voltaje (V)
- Tiempo (ms)
- Distancia (mm)
- Peso (kg)
- Velocidad (cm/s)

---

### 2. Setup documentado

Cada protocolo debe incluir:

- Instrumento utilizado
- Configuración
- Responsable
- Fecha
- Evidencia visual

Ejemplos:

- Multímetro digital
- Calibrador Pie de Rey
- Monitor Serial Arduino
- Cronómetro
- Cámara para evidencia

---

### 3. Criterios definidos antes de probar

El resultado esperado debe establecerse antes de ejecutar el ensayo.

Ejemplo:

| Variable | Criterio |
|---|---|
| Tiempo respuesta | < 2 segundos |
| Error posición | < ±2 mm |
| Caída tensión | < 0.5V |
| Activación seguridad | < 500ms |

---

## 🔍 Evidencias asociadas

| Evidencia | Ubicación |
|---|---|
| Registro fotográfico | `https://drive.google.com/drive/folders/1fICUxhU2f675gIKxcuumZyQAISuapt35?usp=drive_link` |
| Dashboard MAHD | `https://docs.google.com/spreadsheets/d/1olTbqtsNHQLktUmsNjpX3Kluv0PxCd3aXZpZllkpnQA/edit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` |
| Protocolos detallados | `https://docs.google.com/spreadsheets/d/1Qz6l84gm7BfC-t2pQ3CDzLB2sKld-PThRO9EJB8Gyu0/edit?gid=0#gid=0` |
| Retrospectiva IPAC | `https://github.com/imms7/CDIO3_EqBGM_Ascensor-FacultadING/tree/64906521ca02e02b2ccb75d76e8dbfbc6908f9f6/01_Gestion/IPAC` |

---

## Observaciones de Ingeniería

Durante la integración se detectaron riesgos asociados a:

- Posibles vibraciones estructurales
- Caídas de tensión en el L298N
- Desalineación de guías
- Interferencia entre sensores y motor

Las acciones correctivas se documentan formalmente dentro de la retrospectiva IPAC.

---

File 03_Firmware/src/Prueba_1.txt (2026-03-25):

#include <Servo.h>
#include <LiquidCrystal.h>
Servo servo1;
LiquidCrystal lcd(4, 5, 6, 7, 8, 9); //rs, en, d4, d5, d6, d7
int pul_0 = 10;
int pul_1 = 11;
int pul_2 = 12;
int pul[] = {10, 11, 12};
int vpul[] = {1, 1, 1}; // ninguno seleccionado
int actual = 1;
void setup() {
  pinMode(pul[0], INPUT);
  pinMode(pul[1], INPUT);
  pinMode(pul[2], INPUT);
  pinMode(13, OUTPUT);
  pinMode(2, OUTPUT);
  pinMode(A3, OUTPUT);
  pinMode(A0, OUTPUT);
  pinMode(A1, OUTPUT);
  pinMode(A2, OUTPUT);
  servo1.attach(2);
  lcd.begin(16, 2);
  lcd.clear();
  lcd.setCursor(0, 0);
  lcd.print("No. de piso: ");
  delay(1000);
  Serial.begin(9600);
  servo1.write(93);
  lcd.setCursor(13, 0);
  lcd.print("P1");
  analogWrite(A0,255);
  // 0 Y 180 MAX VELOCIDAD EN AMBOS SENTIDOS
  // servo.write(90); DETENER. ENTRE 0 Y 90 SE VA FRENANDO
  // servo.write(180); ANTIHORARIO. ENTRE 90 Y 180 VA ACELERANDO
  // servo.write(0); HORARIO
}
void loop() {
  vpul[0] = digitalRead(pul[0]);
  vpul[1] = digitalRead(pul[1]);
  vpul[2] = digitalRead(pul[2]);
  digitalWrite(13, LOW);
  if (vpul[0] == LOW) { //ir a piso P1
    digitalWrite(13, HIGH);
    lcd.setCursor(13, 0);
    lcd.print("P1");
    switch (actual) {
      case 2:
        servo1.write(0);
        lcd.setCursor(0, 1);
        lcd.print("Bajando");
        delay(1000);
        servo1.write(93);
        lcd.print("       ");
        actual = 1;
        analogWrite(A0,255);
        analogWrite(A1,0);
        analogWrite(A2,0);
        break;
      case 3:
        servo1.write(0);
        lcd.setCursor(0, 1);
        lcd.print("Bajando");
        delay(2000);
        servo1.write(93);
        lcd.print("       ");
        actual = 1;
        analogWrite(A0,255);
        analogWrite(A1,0);
        analogWrite(A2,0);        
      break;
      case 1:
        lcd.setCursor(0, 1);
        lcd.print("Ya estas en P1");
        delay(1000);
        servo1.write(93);
        lcd.print("       ");
        actual = 1;
        analogWrite(A0,255);
        analogWrite(A1,0);
        analogWrite(A2,0);
        break;
    }
    delay(1000);
  }
  else if (vpul[1] == LOW) { // Ir a piso 2
    digitalWrite(13, HIGH);
    lcd.setCursor(13, 0);
    lcd.print("02");
    switch (actual) {
      case 1:
        servo1.write(180);
        lcd.setCursor(0, 1);
        lcd.print("Subiendo");
        delay(1000);
        servo1.write(93);
        lcd.print("       ");
        actual = 2;
        analogWrite(A0,0);
        analogWrite(A1,255);
        analogWrite(A2,0);
      break;
      case 2:
        lcd.setCursor(0, 1);
        lcd.print("Ya estas piso 2");
        delay(1000);
        servo1.write(93);
        lcd.print("       ");
        actual = 2;
        analogWrite(A0,0);
        analogWrite(A1,255);
        analogWrite(A2,0);        
      break;
      case 3:
        servo1.write(0);
        lcd.setCursor(0, 1);
        lcd.print("Bajando");
        delay(2000);
        servo1.write(93);
        lcd.print("       ");
        actual = 2;
        analogWrite(A0,0);
        analogWrite(A1,255);
        analogWrite(A2,0);        
      break;
    }
    delay(1000);
  }
  else if (vpul[2] == LOW) { // Ir a piso 3
    digitalWrite(13, HIGH);
    lcd.setCursor(13, 0);
    lcd.print("03");
    switch (actual) {
      case 2:
        servo1.write(180);
        lcd.setCursor(0, 1);
        lcd.print("Subiendo");
        delay(1000);
        servo1.write(93);
        lcd.print("       ");
        actual = 3;
        analogWrite(A0,0);
        analogWrite(A1,0);
        analogWrite(A2,255);
        break;
      case 1:
        servo1.write(180);
        lcd.setCursor(0, 1);
        lcd.print("Subiendo");
        delay(2000);
        servo1.write(93);
        lcd.print("       ");
        actual = 3;
        analogWrite(A0,0);
        analogWrite(A1,0);
        analogWrite(A2,255);        
      break;
      case 3:
        lcd.setCursor(0, 1);
        lcd.print("Ya estas piso 3");
        delay(1000);
        servo1.write(93);
        lcd.print("       ");
        actual = 3;
        analogWrite(A0,0);
        analogWrite(A1,0);
        analogWrite(A2,255);        
      break;
    }
    delay(1000);
  }
  else {
    digitalWrite(13, LOW);
    lcd.setCursor(0, 1);
    lcd.print("               ");
  }
}

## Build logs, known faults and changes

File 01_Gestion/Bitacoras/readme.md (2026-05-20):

## 📓 Bitácoras de Reunión — Proyecto AscFacultadIng

Para el registro de reuniones y avances del proyecto, se realizaron bitácoras donde se documenta el avance del proyecto.  
Haz clic en cada enlace para ver el detalle de cada sesión:

---

### 📊 Registro de Bitácoras

| # | Bitácora | Acceso |
|---|---|---|
| 1 | Bitácora #1 | [Ver documento](https://docs.google.com/document/d/1QcvhuESDpRqj0MrEmFi_BtyVG4Ju4elA/edit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) |
| 2 | Bitácora #2 | [Ver documento](https://docs.google.com/document/d/1sanbVnEv8253t_jWE68T4xVPjs95nNKE/edit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) |
| 3 | Bitácora #3 | [Ver documento](https://docs.google.com/document/d/1ulVb880UDZR33F8G7zL_vMtP6X6zXxtT/edit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) |
| 4 | Bitácora #4 | [Ver documento](https://docs.google.com/document/d/1NDHhUjU2eix8TDySmXTDF8SkGdwOKdWt/edit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) |
| 5 | Bitácora #5 | [Ver documento](https://docs.google.com/document/d/1oh_W1RaE3F_2ZthSLh5-EtJ9K84l7h0s/edit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) |
| 6 | Bitácora #6 | [Ver documento](https://docs.google.com/document/d/1qhZ-a6zBYLvkI-tTJtK98wP7l4HxAYA9/edit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) |
| 7 | Bitácora #7 | [Ver documento](https://docs.google.com/document/d/1rotOKtKY9fXQJcmG3IHNPgDsNmgM8h4j/edit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) |
| 8 | Bitácora #8 | [Ver documento](https://docs.google.com/document/d/1uTEYpFAGhuTdd4xV16qm_1jHch4gmEzm/edit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) |
| 9 | Bitácora #9 | [Ver documento](https://docs.google.com/document/d/1ulVb880UDZR33F8G7zL_vMtP6X6zXxtT/edit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) |

---

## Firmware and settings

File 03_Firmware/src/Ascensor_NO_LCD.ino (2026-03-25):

#include <Servo.h>

Servo servo1;

int sensorP1 = 2;   // Final de carrera piso 1
int sensorP2 = A7;  // Fototransistor piso 2
int sensorP3 = 4;   // Final de carrera piso 3
int vel = 100;      // Velocidad servo

int pul_0 = 6;  //pulsador Piso 1
int pul_1 = 7;  //pulsador Piso 2
int pul_2 = 8;  //pulsador Piso 3

int pul[] = { 6, 7, 8 };
int vpul[] = { 1, 1, 1 };  // ninguno pulsado
int actual = 0;            //piso actual: deconocido

int sen[] = { 2, A7, 4 };
int vsen[] = { 1, 580, 1 };  // ascensor no detectado

int detener = 90;  // detener servo
int subir = 45;    // girar para subir servo
int bajar = 135;   // girar para bajar servo

void setup() {
  // pullup para pulsadores
  pinMode(pul[0], INPUT_PULLUP);
  pinMode(pul[1], INPUT_PULLUP);
  pinMode(pul[2], INPUT_PULLUP);

  // pullup para sensores
  pinMode(sensorP1, INPUT_PULLUP);
  pinMode(sensorP2, INPUT);
  pinMode(sensorP3, INPUT_PULLUP);

  pinMode(3, OUTPUT);  //pin para Servo
  pinMode(5, OUTPUT);  //pin para Buzzer

  pinMode(A1, OUTPUT);  // pin para Led Verde
  pinMode(A2, OUTPUT);  // pin para Led Amarillo
  pinMode(A3, OUTPUT);  // pin para Led Rojo

  servo1.attach(3);
  servo1.write(90);  //No girar servo

    //identificar en que piso se encuentra la cabina actualmente
  vsen[0] = digitalRead(sen[0]);  // Leer final de carrera primer piso (1 open)
  if (vsen[0] == 0) {
    actual = 1;
    digitalWrite(A1, HIGH);
  }
  vsen[1] = analogRead(sen[1]);  // Leer IRs segundo piso (567 open, 508 close UMBRAL:545) Si este sensor no funciona debes cambiar el umbral
  if (vsen[1] < 545) {           // umbral
    actual = 2;
    digitalWrite(A2, HIGH);
  }
  vsen[2] = digitalRead(sen[2]);  // // Leer final de carrera tercer piso (1 open)
  if (vsen[2] == 0) {
    actual = 3;
    digitalWrite(A3, HIGH);
  }

}

void loop() {

  //Leer pulsadores
  vpul[0] = digitalRead(pul[0]);
  vpul[1] = digitalRead(pul[1]);
  vpul[2] = digitalRead(pul[2]);

    //Leer sensores
  vsen[0] = digitalRead(sen[0]);  // 1 open
  vsen[1] = analogRead(sen[1]);   // 567 open, 508 close UMBRAL:530
  vsen[2] = digitalRead(sen[2]);  // 1 open

    // Encender Led del piso actual
  if (vsen[0] == 0) {
    actual = 1;
    digitalWrite(A1, HIGH);
    digitalWrite(A2, LOW);
    digitalWrite(A3, LOW);
  }
  if (vsen[1] < 545) {
    actual = 2;
    digitalWrite(A1, LOW);
    digitalWrite(A2, HIGH);
    digitalWrite(A3, LOW);
  }
  if (vsen[2] == 0) {
    actual = 3;
    digitalWrite(A1, LOW);
    digitalWrite(A2, LOW);
    digitalWrite(A3, HIGH);
  }
  
  
  Serial.print("Pulsado: ");
  Serial.print(vpul[0]);
  Serial.print(" ");
  Serial.print(vpul[1]);
  Serial.print(" ");
  Serial.print(vpul[2]);
  Serial.println(" ");

  Serial.print("Sensores: ");
  Serial.print(vsen[0]);
  Serial.print(" ");
  Serial.print(vsen[1]);
  Serial.print(" ");
  Serial.print(vsen[2]);
  Serial.println(" ");

  Serial.print("Piso Actual: ");
  Serial.println(actual);

  delay(100);


  //ir a piso P1 --------------------------------------------------------------------------------------------------
  if (vpul[0] == 0) {
    digitalWrite(A1, HIGH);  //Indicador Piso 1
    lcd.setCursor(13, 0);
    lcd.print("P1");
    switch (actual) {
      case 1:
        digitalWrite(A1, HIGH);  //Indicador Piso 1
        digitalWrite(A2, LOW);   //Indicador Piso 2
        digitalWrite(A3, LOW);   //Indicador Piso 3
        tone(5, 450, 250);
        delay(100);
        servo1.write(detener);  // Detener
        break;
      
      case 2:
        digitalWrite(A1, LOW);   //Indicador Piso 1
        digitalWrite(A2, HIGH);  //Indicador Piso 2
        digitalWrite(A3, LOW);   //Indicador Piso 3
        while (vsen[0] == 1) {   //

          digitalWrite(A1, HIGH);  //Indicador Piso 1
          delay(100);
          servo1.write(bajar);  // servo sentido Horario: Bajar
          vsen[0] = digitalRead(sen[0]);
          digitalWrite(A1, LOW);  //Indicador Piso 1
          delay(100);
        }
        servo1.write(detener);
        digitalWrite(A1, HIGH);  //Indicador Piso 1
        actual = 1;
        break;

      case 3:
        digitalWrite(A1, LOW);   //Indicador Piso 1
        digitalWrite(A2, LOW);   //Indicador Piso 2
        digitalWrite(A3, HIGH);  //Indicador Piso 3
        while (vsen[0] == 1) {
          digitalWrite(A1, HIGH);  //Indicador Piso 1
          delay(100);
          servo1.write(bajar);  // servo sentido Horario: Bajar
          vsen[0] = digitalRead(sen[0]);
          digitalWrite(A1, LOW);  //Indicador Piso 1
          delay(100);
        }
        servo1.write(detener);
        digitalWrite(A1, HIGH);  //Indicador Piso 1
        actual = 1;
        break;
    }
    delay(100);
}

  //ir a piso P3 --------------------------------------------------------------------------------------------------
  else if (vpul[2] == 0) {
    digitalWrite(A3, HIGH);  //Indicador Piso 3

    switch (actual) {
      case 3:
        digitalWrite(A1, LOW);   //Indicador Piso 1
        digitalWrite(A2, LOW);   //Indicador Piso 2
        digitalWrite(A3, HIGH);  //Indicador Piso 3

        tone(5, 450, 250);
        delay(100);
        servo1.write(detener);  // Detener

        break;

      case 1:
        digitalWrite(A1, LOW);   //Indicador Piso 1
        digitalWrite(A2, LOW);   //Indicador Piso 2
        digitalWrite(A3, HIGH);  //Indicador Piso 3
        while (vsen[2] == 1) {   //

          digitalWrite(A3, HIGH);  //Indicador Piso 3
          delay(100);
          servo1.write(subir);  // Horario: subir

          vsen[2] = digitalRead(sen[2]);
          digitalWrite(A3, LOW);  //Indicador Piso 3
          delay(100);
        }
        servo1.write(detener);
        digitalWrite(A3, HIGH);  //Indicador Piso 3
        actual = 3;
        break;
      
      case 2:
        digitalWrite(A1, LOW);   //Indicador Piso 1
        digitalWrite(A2, LOW);   //Indicador Piso 2
        digitalWrite(A3, HIGH);  //Indicador Piso 3
        while (vsen[2] == 1) {

          digitalWrite(A3, HIGH);  //Indicador Piso 3
          delay(100);
          servo1.write(subir);  // Horario: Subir

          vsen[2] = digitalRead(sen[2]);
          digitalWrite(A3, LOW);  //Indicador Piso 3
          delay(100);
        }
        servo1.write(detener);
        digitalWrite(A3, HIGH);  //Indicador Piso 3
        actual = 3;
        break;
    }
    delay(100);
  }

    else {
    digitalWrite(13, LOW);
    digitalWrite(3, LOW);

  }
}

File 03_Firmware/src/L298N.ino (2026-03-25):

const int pinIN3 = 7;  
const int pinIN4 = 8;  
const int pinENB = 9;  

void setup() {
  pinMode(pinIN3, OUTPUT);
  pinMode(pinIN4, OUTPUT);
  pinMode(pinENB, OUTPUT);
}

void loop() {

  digitalWrite(pinIN3, HIGH);
  digitalWrite(pinIN4, LOW);
  analogWrite(pinENB, 60);  
  delay(5000);

  digitalWrite(pinIN3, LOW);
  digitalWrite(pinIN4, LOW);
  delay(2000);

  digitalWrite(pinIN3, LOW);
  digitalWrite(pinIN4, HIGH);
  analogWrite(pinENB, 60);  
  delay(5000);

  digitalWrite(pinIN3, LOW);
  digitalWrite(pinIN4, LOW);
  delay(2000);
}

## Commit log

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2026-02-17 Matriz Objetivos y Metas Ascensor
    [Copia de 02 - LAB - Matriz Objetivos y Metas Ascensor.xlsx]
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2026-02-23 Add editable files information to README.md
    Creation of (Archivos editables: KiCad, Altium, Eagle)
2026-02-23 Add hardware description for elevator prototype
    Document the hardware components and structure of the elevator prototype, including critical components and user interface.
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2026-02-23 Create Leyes y normativas - CDIO3docx.pdf
    Adjunto las leyes y normativas usadas en el proyecto
2026-02-23 Create D4-Bloque de Ingenieria (4).dwg1.dwg
    Los planos del bloque de ingenieria se agregan en este commit. Estos planos seran utiles para la creacion de un modelo a escala funcional
    [D4-Bloque de Ingenieria (4).dwg1.dwg]
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2026-02-23 Update project description and team information
    Added current project status and team members.
2026-02-23 Create Pruebasimple_servo.ino
    Aqui agrego una prueba simple que se realizo con el servomotor.
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2026-02-24 Herramientas de auditoria
    Diseno de autor, no les puedo decir como va quedar, pero les puedo dar un adelanto, por que no?
2026-02-24 Create Dossier_V1.txt
    Se sube el archivo Dossier. La mayoria de cambios los hice yo debido a que mi companeras no las deja desde su pc, solo me deja a mi por alguna razon.
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2026-03-01 Add files via upload
    La matriz de requerimientos funcionales y no funcionales describe las funciones principales que debe cumplir el sistema de ascensor propuesto para la Facultad de Ingeniería. En ella se especifican la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
2026-03-01 Add files via upload
    El árbol de problemas y el árbol de objetivos permiten analizar de forma estructurada la situación de accesibilidad en la Facultad de Ingeniería y plantear una solución adecuada.
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2026-03-02 Revise README for hardware prototype description
    Updated the README to enhance the structure and clarity of the hardware description, including sections for components, structure, and user interface.
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2026-04-19 PCB impresa.
    La primera imagen muestra una placa de circuito impreso (PCB) monocara fabricada sobre una lámina de cobre, en la que se observan las pistas conductoras grabadas y varios orificios de montaje o solda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
    La PCB presentada corresponde a una placa de circuito impreso de una sola cara, diseñada para interconectar eléctricamente los componentes del sistema mediante pistas de cobre definidas sobre un sust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
2026-04-19 DiseñoPCB
    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
2026-04-19 Add files via upload
    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
2026-04-19 Create PCB
    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
2026-04-19 Rename 78c4fa99-6bd6-46f2-adef-2dd01baccddb.jpg to PCB 78c4fa99-6bd6-46f2-adef-2dd01baccddb.jpg
    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
2026-04-19 Montaje de pruebas
    El montaje mostrado corresponde a un prototipo de prueba implementado sobre protoboard para validar el funcionamiento del sistema de control. Se emplea una tarjeta Arduino Uno como unidad principal d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
    Arduino Uno
    El Arduino Uno actúa como la unidad de control del sistema. Se encarga de leer las señales provenientes de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
2026-04-19 Construcción de una estructura física en MDF
    Estructura física de la maqueta
    Como parte del desarrollo del proyecto, se planteó la construcción de una estructura física en MDF para representar el entorno del sistema. Dentro de esta maqueta, las escaleras constituyen un elemento clave, ya que modelan la conexión actual entre pisos y permiten evidenciar la disposición espacial de la edificación. La estructura incluye base de soporte, peldaños y barandas laterales, conformando un módulo estable y funcional que facilita la visualización del problema de accesibilidad vertical.
    Función de las escaleras en la maqueta
    Las escaleras actúan como representación del acceso existe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
2026-05-01 Conversion de pesos.
    Para las pruebas de funcionamiento del prototipo se estableció una carga máxima de 55 g, correspondiente a una condición de uso representativa compuesta por 30 g para una persona usuaria de silla de 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
    En términos funcionales, esta carga representa una situación real aproximada de 155 kg, considerando como referencia una persona usuaria de silla de ruedas de 70 kg, una silla manual de 15 kg y un ac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
2026-05-02 Conversion del peso de kg a g.
    Con el fin de validar experimentalmente el funcionamiento del sistema de elevación a escala, se realizaron pruebas reales de carga sobre el prototipo desarrollado. Estas pruebas tuvieron como objetiv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
    El prototipo utilizado presenta unas dimensiones aproximadas de 21 cm de altura, 13 cm de profundidad y 6 cm de ancho, y está compuesto por una estructura principal en MDF, piezas específicas impresa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
2026-05-04 Update readme.md by removing project note
    Removed note about project traceability and decision-making.
2026-05-19 Enhance README with build instructions for Arduino
    Added detailed build and upload instructions for Arduino. - by Brayan
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2026-05-23 Revise readme for MAHD project updates
    Updated the readme to reflect the current status and details of the MAHD project, including project phases, risks, and upcoming milestones.
2026-05-24 Update BOM with detailed components and costs
    This document details all electronic, electromechanical components, manufacturing materials, and estimated costs needed to assemble one unit of the Elevator System for the Faculty of Engineering at U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
2026-05-26 Revise README for project details and structure
    Updated the README to provide detailed project information, including introduction, value proposition, functional requirements, and prototype image placeholder. - By : Brayan
2026-05-26 Revise project title and enhance README content
    Updated project title and refined project description. Added a section comparing functional requirements with prototype achievements. - By : Brayan
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
